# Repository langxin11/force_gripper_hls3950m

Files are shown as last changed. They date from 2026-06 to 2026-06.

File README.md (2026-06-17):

# 基于飞特 HLS3950 的双指力控夹爪

面向飞特 HLS3950 总线舵机的双指力控夹爪项目，包含可测试控制核心、Python 上位机和机械适配资料。当前 CAD 和台架验证以 `HLS3950M-C001` 为基准，官网商品页也写作 `HL-3950-C001`；外形尺寸为 `45.22 mm × 24.72 mm × 35 mm` 且安装、输出轴、通信和供电接口匹配的飞特舵机也可作为候选，例如 `ST-3250-C001`、`ST-3235-C001` 和 `HL-3930-C001`。

> 当前状态：架构与可测试控制骨架已建立，HLS3950 机械适配 CAD 已基本完成；下一阶段使用电脑、飞特 URT-1 和 `vassar-feetech-servo-sdk==1.5.0` 完成尺寸复核、样机装配与真机台架验证。

## 项目来源

本项目基于 [`Shua-Kang/force_gripper_hardware`](https://github.com/Shua-Kang/force_gripper_hardware)
改造而来，当前重点是将原机械结构适配到飞特 HLS3950 及同尺寸候选舵机，并补充控制软件、接线说明和装配文档。
原参考仓库未见明确 `LICENSE` 文件，相关 STEP、STL 和图片资料的使用限制见 [hardware/README.md](hardware/README.md)。

## 仓库结构

```text
firmware/   可移植 C++ 控制核心与单元测试
software/   Python SDK、命令行工具和上位机测试
hardware/   CAD、打印件、接线图和 BOM
docs/       中文架构、适配、装配与开发文档
```

## 快速验证

```bash
cmake -S firmware -B build/firmware
cmake --build build/firmware
ctest --test-dir build/firmware --output-on-failure
uv run --project software --extra dev pytest software/tests -v
```

如果只验证 Python 上位机：

```bash
uv run --project software --extra dev pytest software/tests -v
```

更多开发命令（包括文档构建、静态检查）见[开发与测试](docs/development.md)。

## 文档

- [项目文档首页](docs/index.md)
- [主机通信协议](docs/host-protocol.md)
- [HLS3950 通信适配](docs/hls3950-adaptation.md)
- [机械设计与装配](docs/mechanical.md)
- [URT-1 接线](docs/urt1-wiring.md)
- [开发与测试](docs/development.md)

严格构建文档或启动本地预览：

```bash
uv run --project software --extra docs mkdocs build --strict
uv run --project software --extra docs mkdocs serve
```

## 开源许可

本仓库原创代码、文档和新增设计说明采用 [Apache License 2.0](LICENSE) 发布。
来自 `Shua-Kang/force_gripper_hardware` 的参考 STEP、STL 和图片资料，以及飞特官网图片/PDF 等第三方资料不自动纳入本仓库 Apache-2.0 许可；这些资料的使用限制以其来源说明为准。

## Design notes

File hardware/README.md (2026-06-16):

# 硬件目录

本目录用于存放 HLS3950 版本的机械和电气设计。

- `cad/`：参数化源文件和中性格式 STEP 文件。
- `print_parts/`：经过版本标记的 STL/3MF 打印文件。
- [`BOM.md`](BOM.md)：HLS3950 版本首版样机物料清单。
- `cad/force_gripper_xl430.step`：导入 Onshape 的原 XL430 夹爪装配参考模型。
- `print_parts/` 下的原始 STL：仅用于尺寸和装配校核，不代表已经适配 HLS3950。
- 后续增加接线图、皮带轮工程图和装配公差表。

当前机械适配在 [Onshape 文档](https://cad.onshape.com/documents/6b62f8794d0bbb7b41c1c997/w/e1534e929e40aaacf2109eb3/e/1d43023ae86ad55792d145ee) 中维护。CAD 已基本完成，尚待实物尺寸复核、打印和装配验证。

已实施的核心变更：

- 重新绘制与飞特 HLS3950 连接的基体，使安装孔位匹配舵机。
- 从动轮与基体左右安装耳改用 `5 mm × 35 mm` 光杆、`M4` 螺纹的塞打螺栓，不再使用圆柱销。
- 主动轮改为以轴心为中心、半径 `7 mm`（节圆直径 `14 mm`）的四孔圆周阵列，使用 `M3` 螺丝与舵机连接。

改造参数、复用范围和装配图片统一见[机械设计与装配](../docs/mechanical.md)。

## 参考模型来源

参考文件来自 [`Shua-Kang/force_gripper_hardware`](https://github.com/Shua-Kang/force_gripper_hardware)
提交 `ff68bf4fce071ca1d055616c89dba56ccfd226d8`。该参考仓库当前没有明确的许可证文件，
因此这些文件只用于本项目内部改型和尺寸校核，不受本仓库 Apache-2.0 许可覆盖；公开发布、再分发或商业使用前必须取得原作者授权。

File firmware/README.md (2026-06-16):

# 固件控制核心

可移植 C++17 夹爪控制核心，通过抽象 `ServoBus` 接口与舵机层解耦。

## 结构

```text
core/include/    公开头文件（GripperController、ServoBus 接口）
core/src/        控制核心实现
tests/           单元测试（含 FakeServoBus）
```

## 编译与测试

```bash
cmake -S firmware -B build/firmware
cmake --build build/firmware
ctest --test-dir build/firmware --output-on-failure
```

不依赖硬件，可在任何 C++17 环境编译运行。

## 文档

架构设计见[总体架构](../docs/architecture.md)，开发流程见[开发与测试](../docs/development.md)。

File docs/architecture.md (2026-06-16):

# 总体架构

控制核心使用标准 C++17，通过抽象的 `ServoBus` 访问舵机；具体协议、未来控制板实现和上位机接口与控制逻辑解耦。这样可以在无硬件环境测试状态机，也能在更换通信方案时保留控制逻辑。

## 分层

| 层级 | 职责 | 不应承担的职责 |
| --- | --- | --- |
| 机械与电气 | 安装、传动、供电、接线和散热 | 控制协议和上位机业务逻辑 |
| 舵机总线适配 | HLS3950 帧、寄存器、超时和单位换算 | 夹爪状态机和 ROS 接口 |
| 控制核心 | 双电机协调、限幅、故障处理和后续力控 | 串口驱动和具体寄存器地址 |
| 控制板应用 | 调度控制周期、解析主机命令、发布状态 | 机械参数的隐式硬编码 |
| Python SDK | 稳定的初始化、使能、位置和状态 API | 直接访问舵机总线 |
| ROS 适配 | ROS 话题、服务和参数桥接 | 重复实现控制算法 |

## 数据流

```text
Python/ROS
    | 高层 JSON Lines 命令
控制板应用
    | 调用控制 API
GripperController
    | ServoBus 接口
HLS3950 总线适配
    | 半双工串口
两台 HLS3950
```

命令格式和错误语义详见[主机通信协议](host-protocol.md)。

## 安全边界

- 默认输出关闭，初始化成功后才允许使能。
- 输出在控制核心统一限幅，初始上限为额定范围的 25%。
- 任一电机通信失败时，两侧同时停止并关闭扭矩。
- 故障不能靠下一条普通运动命令自动清除。
- 真机测试必须脱离夹爪传动机构或设置机械限位保护。

当前台架由电脑经 URT-1 运行 `vassar-feetech-servo-sdk==1.5.0`，直接控制 HLS3950。
上图中的 C++ `ServoBus` 数据流对应未来板级控制路线；具体 MCU 或控制板尚未选定。

## 参见

- [HLS3950 通信适配](hls3950-adaptation.md)：舵机底层 SDK 选型和台架验证。
- [主机通信协议](host-protocol.md)：控制板与上位机之间的 JSON Lines 命令定义。
- [开发与测试](development.md)：控制核心的编译测试流程。

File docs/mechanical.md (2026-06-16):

# 机械设计与装配

当前 HLS3950 机械适配已在 [Onshape CAD](https://cad.onshape.com/documents/6b62f8794d0bbb7b41c1c997/w/e1534e929e40aaacf2109eb3/e/1d43023ae86ad55792d145ee) 中基本完成，待实物尺寸复核、打印和装配验证。当前基准型号为 `HLS3950M-C001`，官网商品页也写作 `HL-3950-C001`。同外形尺寸 `45.22 mm × 24.72 mm × 35 mm` 且安装、输出轴、通信和供电接口匹配的飞特舵机也可作为机械候选，例如 `ST-3250-C001`、`ST-3235-C001` 和 `HL-3930-C001`。

## 已实施变更

| 部位 | 当前设计 | 样机检查重点 |
| --- | --- | --- |
| 安装基体 | 按 HLS3950 安装孔位重新绘制 | 孔距、输出轴中心、出线空间和结构强度 |
| 主动轮 | 4 个 M3 孔，孔中心半径 7mm，PCD 14mm | 螺丝长度、避空、防松和同轴度 |
| 从动轮轴 | 5mm × 35mm 光杆、M4 螺纹塞打螺栓 | 光杆覆盖轴承承载区，螺纹不接触轴承工作面 |

还需确认机械限位、皮带张紧量、动力配电安装位，以及舵机和线束与机器人法兰、相机支架的全行程干涉。

## 复用范围

原 XL430 项目的以下内容可作为首版样机参考：

| 内容 | 处理 |
| --- | --- |
| MGN12H 导轨、滑块、指尖支架和 TPU 指尖 | 原则上复用，装配后检查干涉 |
| HTD3M 皮带、从动轮和 F685-2RS 轴承 | 保持传动中心距时复用，最终长度需复核 |
| 指尖、滑块和皮带装配顺序 | 可参考，张紧量和行程需重新验证 |
| 原基体、XL430 主动轮、圆柱销装配和 OpenRB 接线 | 不复用 |

## 打印与装配参考

刚性零件可先用 PLA、PETG 或 ABS，指尖使用 TPU 95A。HLS3950 新基体和主动轮的材料、层方向和填充率需通过样机试验确定。

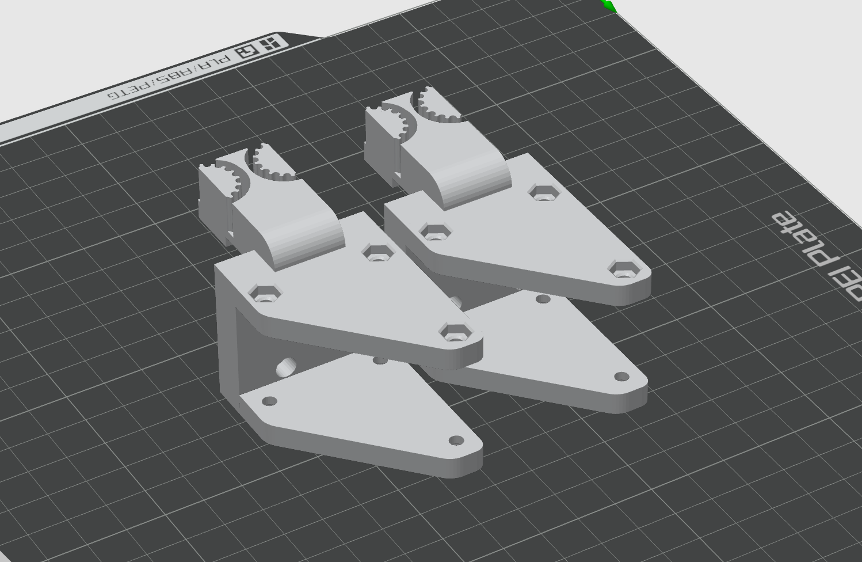
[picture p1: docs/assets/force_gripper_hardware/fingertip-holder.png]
原项目指尖支架打印方向


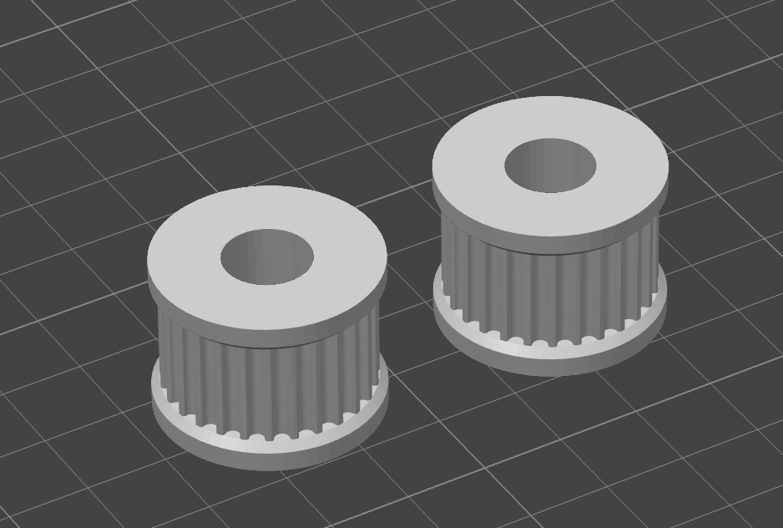
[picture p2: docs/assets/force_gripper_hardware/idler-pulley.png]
原项目从动轮打印方向


从动轮本体可参考，轴和安装方式以当前塞打螺栓方案为准。

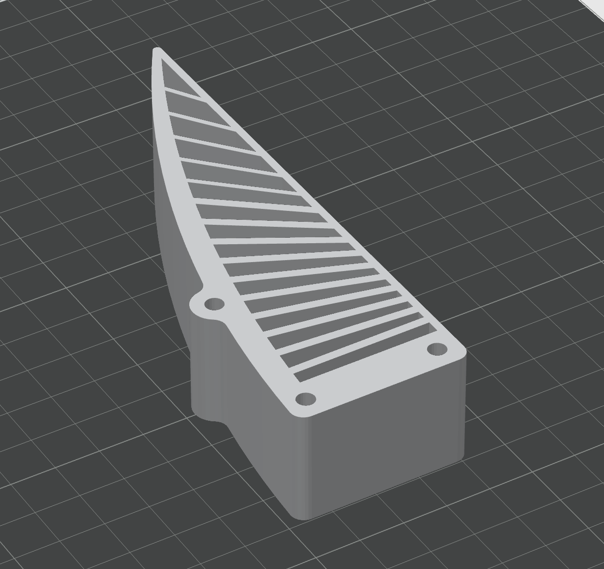
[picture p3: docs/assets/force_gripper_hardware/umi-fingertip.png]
原项目 TPU 指尖打印方向


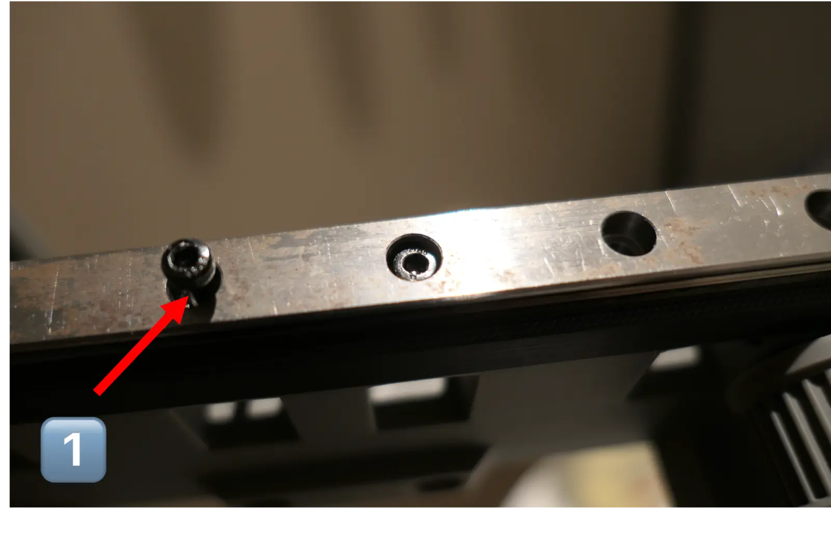
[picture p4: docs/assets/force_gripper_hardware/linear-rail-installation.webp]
原项目线性导轨安装


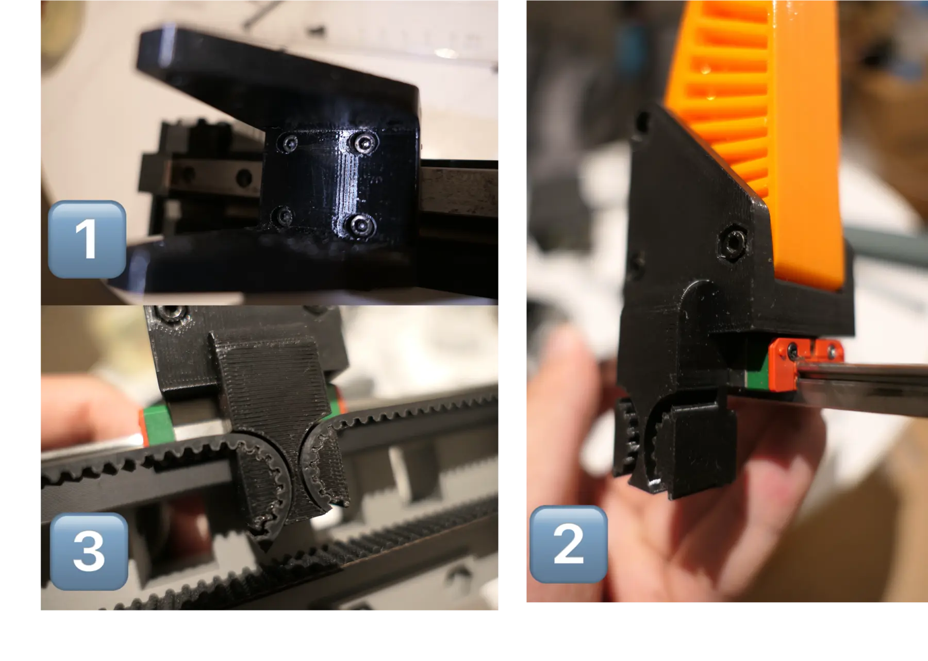
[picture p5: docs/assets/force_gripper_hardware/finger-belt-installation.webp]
原项目指尖和同步带装配


装配后检查导轨螺丝不进入滑块行程，皮带全行程无跳齿、跑偏和干涉。

## 发布前检查

1. 使用 HLS3950 实物复核安装孔、输出轴中心和连接器空间。
2. 确认主动轮、从动轮和皮带夹持点共面，并保留张紧调节量。
3. 确认塞打螺栓光杆覆盖轴承承载区。
4. 验证左右滑块全行程和实体机械限位。
5. 导出完整装配至 `hardware/cad/hls3950_gripper.step`（当前待生成），并将新增打印件导出到 `hardware/print_parts/`。

## 来源限制

参考 STEP、STL 和图片来自 [`Shua-Kang/force_gripper_hardware`](https://github.com/Shua-Kang/force_gripper_hardware) 提交 `ff68bf4fce071ca1d055616c89dba56ccfd226d8`。原仓库没有明确许可证；这些参考资料不受本仓库 Apache-2.0 许可覆盖。公开发布衍生模型或图片前需取得作者授权，或替换为本项目自行生成的资料。图片对应关系见 `docs/assets/force_gripper_hardware/PROVENANCE.txt`。

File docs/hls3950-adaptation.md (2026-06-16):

# HLS3950 通信适配

## 当前路线

电脑通过 `URT-1` 直接连接两台 HLS3950，当前选用社区维护的
[`vassar-feetech-servo-sdk==1.5.0`](https://github.com/vassar-robotics/feetech-servo-sdk)。
该版本同时提供高层 `ServoController` 和底层 `scservo_sdk.hls`。

安装真机依赖：

```bash
uv sync --project software --extra hardware
```

截至 2026-06-15，依赖来源的核对结果如下：

| 来源 | HLS 支持 | 结论 |
| --- | --- | --- |
| 官方 GitHub `FTServo_Python` | 包含 `scservo_sdk/hls.py` 和 `hls/` 示例 | 用于核对底层实现 |
| 官方 PyPI `ftservo-python-sdk==2.0.0` | wheel 和 sdist 均缺少 `scservo_sdk/hls.py` | 不能用于 HLS3950 |
| 社区 PyPI `vassar-feetech-servo-sdk==1.5.0` | wheel 和 sdist 均包含 HLS | 本项目当前选型 |

社区包内置的整个 `scservo_sdk` 目录与飞特官方提交
`a203373036723e0d98c6c49b67cf09a9ee299220` 逐文件一致，可以替代 Git 依赖。
它同样安装顶层 `scservo_sdk` 包，不应与 `ftservo-python-sdk` 同时安装。

当前直接使用社区包的 `ServoController` 开展台架验证，不额外实现包装层。使用时必须明确其行为：

- `connect()` 会检查各舵机相位，并把非零相位改为 `0`。
- `write_position()` 和 `write_torque()` 会按需切换工作模式并使能扭矩。
- `disconnect()` 会关闭所有已配置舵机的扭矩。
- 电流单位、扭矩方向和保护行为仍需使用 HLS3950 实物验证。

```text
电脑 -> USB -> 飞特驱动板/URT -> HLS3950 总线
                    |
                 外部 12V 电源
```

完整供电和引脚要求见 [URT-1 接线](urt1-wiring.md)。USB 串口不保证硬实时，控制频率和急停策略必须通过实测确定。

## 已确认信息

| 项目 | 当前结论 |
| --- | --- |
| 接口 | 三线 TTL，`5264-3P`，GND/Vcc/Signal |
| 电压 | 9V 至 12.6V，正式系统按 12V 设计 |
| 位置范围 | 0 至 4096 对应 360 度 |
| 输出接口 | 25T，外径约 5.9mm |
| SDK 能力 | 位置、速度和同步位置写入 |
| 底层地址 | 模式 33、目标扭矩 44、当前电流 69，仍需按手册和实机核对单位与行为 |

## 软件使用边界

当前仓库尚未实现 HLS3950 专用传输类。台架程序可以直接调用 `ServoController`；夹爪级的双机协调、行程限制、故障联停和力控逻辑仍属于本项目，不由通用舵机 SDK 代替。

## 台架验证顺序

1. 单机只读：扫描 ID，读取型号、位置、电压和温度。
2. 单机低输出：验证扭矩开关、方向、单位和限幅。
3. 单机保护：验证超时、断线、过流和过温行为。
4. 双机通信：验证轮询频率、总线冲突和最坏响应时间。
5. 脱离传动机构完成连续运行测试。
6. 接入皮带后从 10% 输出开始标定开合方向和行程。

## 未决问题

- 寄存器、错误码、反馈单位和符号需与对应硬件版本手册逐项核对。
- HLS3950 是否能以目标频率同时返回位置和电流。
- 恒流模式能否稳定用于低速夹持。
- URT-1 的动力通道持续载流能力，尤其是双机堵转附近的温升。
- URT-1 在双机 1 Mbps 下的稳定性和最大反馈频率。

## 官方资料

- [飞特 HLS3950 产品页与规格书入口](https://www.feetechrc.com/563788.html)
- [飞特 FTServo_Python](https://github.com/ftservo/FTServo_Python)
- [FTServo_Python HLS 模块](https://github.com/ftservo/FTServo_Python/blob/a203373036723e0d98c6c49b67cf09a9ee299220/scservo_sdk/hls.py)
- [官方 PyPI：ftservo-python-sdk](https://pypi.org/project/ftservo-python-sdk/)
- [社区 SDK：vassar-feetech-servo-sdk](https://github.com/vassar-robotics/feetech-servo-sdk)

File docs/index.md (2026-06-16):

# 基于飞特 HLS3950 的双指力控夹爪

本项目使用两台飞特 HLS3950 总线舵机构建双指力控夹爪，目标是让控制、通信和机械设计均可独立验证。当前设计以 `HLS3950M-C001` 为基准，官网商品页也写作 `HL-3950-C001`；外形尺寸为 `45.22 mm × 24.72 mm × 35 mm` 且安装、输出轴、通信和供电接口匹配的飞特舵机也可作为候选，例如 `ST-3250-C001`、`ST-3235-C001` 和 `HL-3930-C001`。

## 当前状态

- 软件：C++ 控制核心、Python SDK、CLI、仿真后端和自动测试已建立。
- 机械：HLS3950 基体、主动轮和从动轮结构的 CAD 适配已基本完成。
- 下一步：复核实物尺寸，完成打印装配，并验证 URT-1 双机通信、供电和反馈频率。

## 阅读顺序

1. [总体架构](architecture.md)与[主机通信协议](host-protocol.md)：了解软件分层、安全策略和命令格式。
2. [HLS3950 通信适配](hls3950-adaptation.md)与 [URT-1 接线](urt1-wiring.md)：进行台架测试。
3. [机械设计与装配](mechanical.md)：查看 CAD 变更、复用件和装配要求。
4. [开发与测试](development.md)：运行测试和提交前检查。

在完成官方资料核对和样机验证前，不假设 HLS3950 兼容 DYNAMIXEL，也不把恒流模式直接等同于夹持力控制。

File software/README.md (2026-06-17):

# HLS3950 Gripper Python SDK

HLS3950 力控夹爪的 Python 上位机 SDK 和命令行工具。

## 目录结构

```text
src/hls3950_gripper/    SDK 包（client、transport、cli）
tests/                   单元测试
```

## 快速开始

零依赖仿真测试：

```bash
uv run --project software --extra dev pytest software/tests -v
PYTHONPATH=software/src python3 -m hls3950_gripper.cli --simulate status
```

真机台架依赖（需要 HLS3950 和 URT-1）：

```bash
uv sync --extra hardware
```

## 文档

完整设计、协议和开发流程见[项目文档](../docs/index.md)。

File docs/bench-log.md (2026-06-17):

# HLS3950 台架记录

## 2026-06-17 双机装带后验证

- 两台舵机已完成 ID 分配：左侧 `ID 1`，右侧 `ID 2`。
- 重新安装同步带前，两台舵机先转到中位 `2047`。
- 同步带安装后，只读轮询确认两台舵机均稳定在 `position=2047` 附近。
- 双机 `close --delta 20` 验证通过：两台舵机均向闭合方向运动，最终误差约 `1-2` tick。
- 双机 `open --delta 20` 验证通过：两台舵机均回到中位附近，最终误差约 `0-1` tick。
- 当前方向映射：`open` 为两台舵机位置减小，`close` 为两台舵机位置增大。
- 当前软件全开参考位暂定为 `left.open_position=2047`、`right.open_position=2047`。
- `close_position` 尚未完成标定，不能用于归一化控制。

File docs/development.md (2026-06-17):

# 开发与测试

## 固件核心

控制核心只依赖标准 C++17，可以在没有控制板和舵机的电脑上编译测试：

```bash
cmake -S firmware -B build/firmware
cmake --build build/firmware
ctest --test-dir build/firmware --output-on-failure
```

新增控制逻辑时，应先使用 `FakeServoBus` 覆盖正常、断线和部分写入失败场景，再接入后续真实总线实现。

## Python 上位机

零依赖测试和仿真命令：

```bash
uv run --project software --extra dev pytest software/tests -v
PYTHONPATH=software/src python3 -m hls3950_gripper.cli --simulate status
```
pytest 兼容 unittest.TestCase，无需改写已有测试。

开发环境安装：

```bash
uv venv
uv pip install -e 'software[dev,docs]'
```

## 提交前检查

首次安装 Git 提交钩子：

```bash
uv run --project software --extra dev pre-commit install
```

钩子会在提交时检查基础文件格式、YAML 和 Python Ruff 规则。也可以手动检查仓库中的全部文件：

```bash
uv run --project software --extra dev pre-commit run --all-files
```

完整检查包括固件与上位机测试、静态检查和文档严格构建：

```bash
cmake -S firmware -B build/firmware
cmake --build build/firmware
ctest --test-dir build/firmware --output-on-failure
uv run --project software --extra dev pytest software/tests -v
uv run --project software --extra docs mkdocs build --strict
uv run --project software --extra dev pre-commit run --all-files
uv run --project software --extra dev mypy software/src
```

依赖下载需要网络；基础 C++ 和 Python 单元测试不需要下载第三方依赖。

如果本机环境会让 `pytest` 自动加载外部插件并导致冲突，可以只对当前命令临时禁用自动加载：

```bash
PYTEST_DISABLE_PLUGIN_AUTOLOAD=1 uv run --project software --extra dev pytest software/tests -v
```

## 参见

- [总体架构](architecture.md)：控制核心的分层设计和安全边界。
- [主机通信协议](host-protocol.md)：命令格式和错误语义。
- [HLS3950 通信适配](hls3950-adaptation.md)：真机 SDK 安装和台架验证顺序。

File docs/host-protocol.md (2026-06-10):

# 主机通信协议

控制板与上位机使用 UTF-8 JSON Lines：每条请求和响应都是一行完整 JSON，以换行符结束。该协议只表达夹爪级命令，不暴露 HLS3950 寄存器。

## 通用响应

成功：

```json
{"ok":true,"status":{"initialized":true,"enabled":false,"fault":null,"left_position":0,"right_position":0}}
```

失败：

```json
{"ok":false,"error":"controller_disabled"}
```

## 命令

初始化：

```json
{"command":"initialize"}
```

使能和关闭：

```json
{"command":"enable"}
{"command":"disable"}
```

查询状态：

```json
{"command":"status"}
```

归一化位置命令：

```json
{"command":"position","left":0.25,"right":0.75}
```

`left` 和 `right` 范围为 `0.0` 到 `1.0`。具体开合方向由标定参数决定，不由上位机猜测电机正反方向。

## 兼容性规则

- 新增字段时，接收方应忽略不认识的可选字段。
- 删除字段或改变字段含义属于破坏性变更，需要增加协议版本。
- 错误使用稳定的机器可读字符串；中文解释由上位机根据错误码显示。
- 控制板必须限制单行最大长度，并对无效 JSON 返回错误而不是执行部分命令。

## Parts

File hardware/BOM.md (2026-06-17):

# HLS3950 力控夹爪 BOM

本文档列出 HLS3950 版本样机物料。

## 电机、控制与通信

| 名称 | 推荐规格 | 数量 | 状态 | 备注 |
| --- | --- | ---: | --- | --- |
| 飞特总线舵机 | HLS3950M-C001，TTL，25T/OD5.9mm 输出花键 | 2 | 必需 | 官网商品页也写作 `HL-3950-C001`；同尺寸兼容候选：`ST-3250-C001`、`ST-3235-C001`、`HL-3930-C001`。 |
| 飞特 USB 总线板 | URT-1 或 URT-2 | 1 | 必需 | 当前原型使用 URT-1。 |
| USB 数据线 | 支持数据传输，接口按总线板实物选择 | 1 | 必需 | URT-1 常见 Mini USB，URT-2 常见 USB-C。 |
| HLS3950 舵机线束  | 5264-3P，GND/Vcc/Signal-TTL | 2 | 可复用 | 舵机自带；不要只按线色接线。 |
| TTL 总线分线/端子 | 3 线并联，GND/Vcc/Signal | 1 | 待 CAD 确认 | 当前原型接法：`12V -> URT-1 DC6V-9V/V1 -> TTL G/S/V -> HLS3950`。 |

## 供电与保护

| 名称 | 推荐规格 | 数量 | 状态 | 备注 |
| --- | --- | ---: | --- | --- |
| 12V 稳压电源 | 12V，至少 6A | 1 | 必需 | 两台舵机堵转电流合计约 4.8A。 |
| 支路保险或电子限流 | 每路按实测峰值选型 | 2 | 必需 | 建议每台舵机独立保护。 |
| 电源线 | 20-22 AWG 或按实测电流升级 | 若干 | 待 CAD 确认 | 按电流与布线长度确定。 |

## 机械传动与标准件

| 名称 | 推荐规格 | 数量 | 状态 | 备注 |
| --- | --- | ---: | --- | --- |
| 线性导轨与滑块 | MGN12H，200mm，含 2 个滑块 | 1 | 可复用 | 沿用原 BOM。 |
| 同步带 | HTD3M，约 1m | 1 | 可复用 | 长度需 CAD 复核。 |
| 法兰轴承 | F685-2RS，5x11x5mm | 2 | 可复用 | 从动同步轮用。 |
| 塞打螺栓 | 光杆直径 5mm，光杆长度 35mm，M4 螺纹 | 1 | 待样机验证 | 从动轮轴。 |
| HTD3M 主动皮带轮 | 四个 M3 连接孔，孔中心半径 7mm，PCD 14mm | 2 | 待样机验证 | 复核孔位、避空和同轴度。 |
| 从动同步轮 | 沿用原 `idler_pulley` 设计 | 1 | 可复用 | 沿用原设计。 |
| 指尖固定座 | 沿用原指尖支架设计 | 2 | 可复用 | 检查限位与干涉。 |
| TPU 指尖 | UMI/FlexiTac 兼容指尖 | 2 | 可复用 | 按传感器需求调整。 |

## 3D 打印件

| 名称 | 数量 | 状态 | 备注 |
| --- | ---: | --- | --- |
| HLS3950 安装基体 | 1 | 待样机验证  | 复核孔径、孔距和出线空间。 |
| HTD3M 主动轮打印体 | 2 | 待样机验证  | 复核强度和偏心。 |
| 从动同步轮 | 1 | 可复用 | `idler_pulley.stl`。 |
| 指尖支架 | 2 | 可复用 | `gripper_fingertip_holder.stl`。 |
| TPU 指尖 | 2 | 可复用 | `umi_fingertip.stl`。 |
| Franka 或 KUKA 法兰转接件 | 1 | 可复用 | 按实际机器人选型。 |
| RealSense 相机支架 | 1 | 可选 | 需要相机时使用。 |
| 配电/URT-1 安装盒 | 1 | 待 CAD 确认 | 按 URT-1 与线束重新设计。 |
| 机械限位或缓冲块 |  2-4 | 必需 | 先于硬碰撞接触。 |

## 紧固件与装配辅料

| 名称 | 推荐规格 | 数量 | 状态 | 备注 |
| --- | --- | ---: | --- | --- |
| M3 螺丝套装 | M3 x 8/10/20/35mm，含螺母 | 1 套 | 可复用 | 新增电机座长度需复核。 |
| HLS3950 安装螺丝 | M2x6mm |  4-8 | 待样机验证  | XL430 的 M2.5 螺丝不能沿用。 |
| 金属螺母或热熔螺母 | 304 六角螺母 M3/M6 | 若干 | 待 CAD 确认 | 反力位置优先用金属件。 |
| 主动轮连接螺丝 | M3，长度按舵机连接面和主动轮厚度选定 | 8 | 待样机验证  | 每个主动轮 4 颗。 |
| M6 法兰安装螺丝 | M6 x 12mm，按机器人法兰选型 |  2-4 | 可复用 | 按机器人法兰选型。 |
| 扎带、胶带、热缩管 | 常规规格 | 若干 | 必需 | 线束固定与应力释放。 |

## 不再作为当前主 BOM 的原 XL430 物料

| 原物料 | HLS3950 版本处理 |
| --- | --- |
| XL430-W250-T | 替换为 2 台 HLS3950M-C001。 |
| 原控制板 | 当前替换为 URT-1。 |
| XL430 随附 M2.5 螺丝 | 不能用于 HLS3950 安装。 |
| XL430 四孔输出盘接口 | 改为四个 M3 孔、半径 7mm、PCD 14mm 的 HLS3950 接口。 |
| 原控制板安装盒 | 不建议直接复用。 |

## 采购前检查项

1. 复核舵机安装孔径、孔距、轴心和出线空间。
2. 复核主动轮孔位、螺丝长度和避空。
3. 复核从动轮轴承与塞打螺栓配合。
4. 按实测电流确定保险、线径和电源余量。
5. 检查舵机、法兰、相机支架和手指张开位干涉。
6. 保留实体机械限位。

## 参考文档

- [HLS3950 通信适配](../docs/hls3950-adaptation.md)
- [URT-1 与 HLS3950 接线](../docs/urt1-wiring.md)
- [机械设计与装配](../docs/mechanical.md)

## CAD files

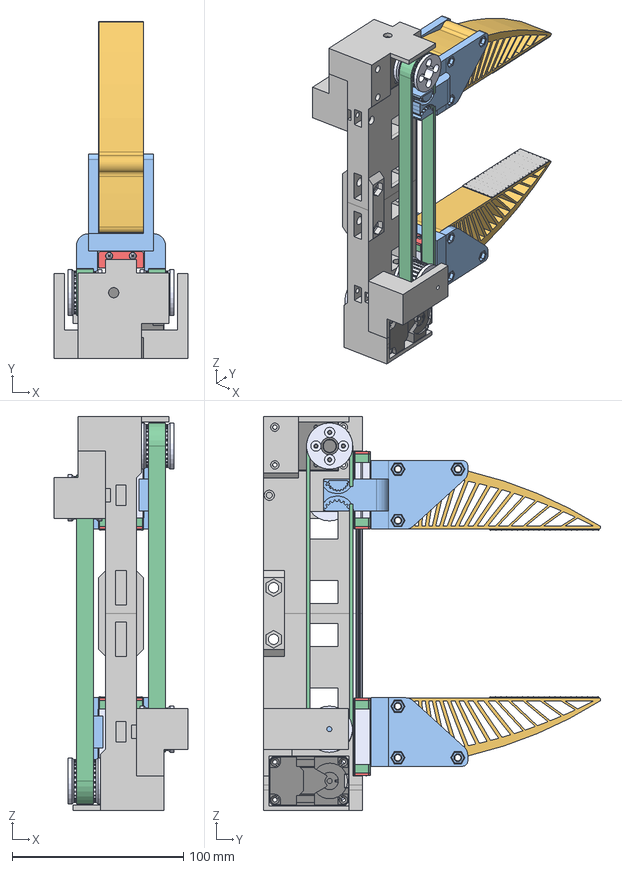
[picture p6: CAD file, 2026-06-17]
hardware/cad/force_gripper_xl430.step
78.0 x 197.0 x 230.0 mm
MGN12 LINEAR GUIDE RAIL, CONFIGURABLE_200 mm x 2
MGN12H, LINEAR GUIDE BLOCK x 2
DC11_A01_DUMMY x 3
DX124_SCREW-COVER x 2
B3B-EH x 4
DC11_A01_CASE_CVR_DUMMY x 2
DC11_A01_IDLER_DUMMY x 2
DC11_A01_IDLER_CAP_DUMMY x 2
DC11_A01_IDLER_SCREW x 2
FHS_M2_5X10 x 16
DC11_A01_SPACER_DUMMY x 16
base x 2
gt2 pulley v1 (1)
HTD3.0 Pulley 18_T 12.000000000000002mm_Belt x 2
HTD3.0 Pulley 27_T 12.000000000000002mm_Belt x 2
HTD3.0 Pulley 18_T 12.000000000000002mm_Belt(Mirror) x 2
holder x 2
soft_gripper_finger x 2
HTD3.0 Pulley 27_T 12.000000000000002mm_Belt (1) x 2
tactilepad x 2

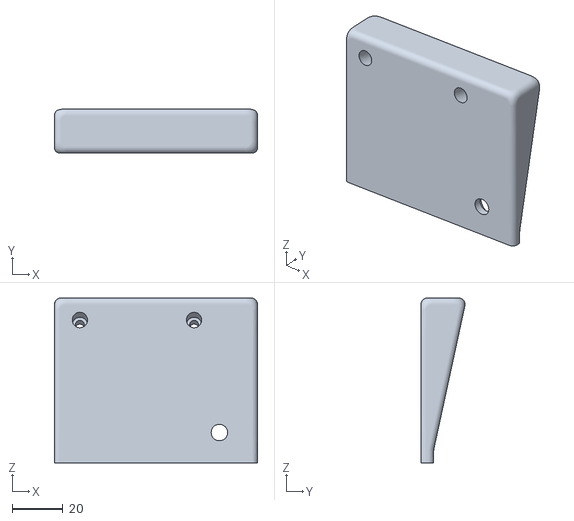
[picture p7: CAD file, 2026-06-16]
hardware/print_parts/realsense_camera_mount.stl
80.0 x 17.4 x 65.0

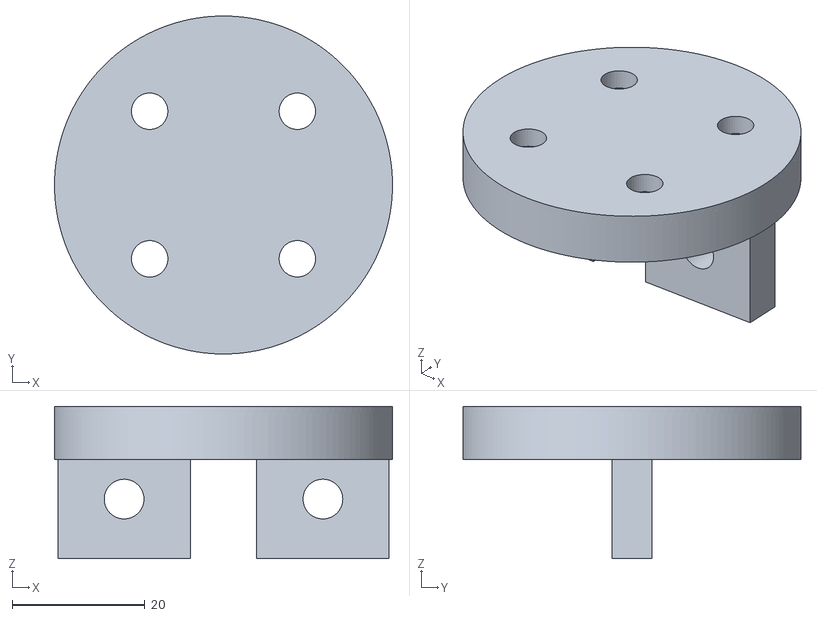
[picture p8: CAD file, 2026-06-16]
hardware/print_parts/kuka_connector.stl
51.0 x 51.0 x 23.0

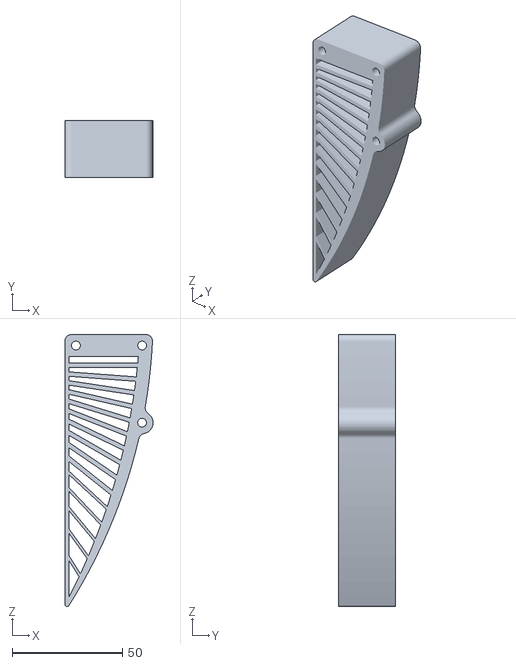
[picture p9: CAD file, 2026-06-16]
hardware/print_parts/umi_fingertip.stl
40.0 x 25.8 x 123.4

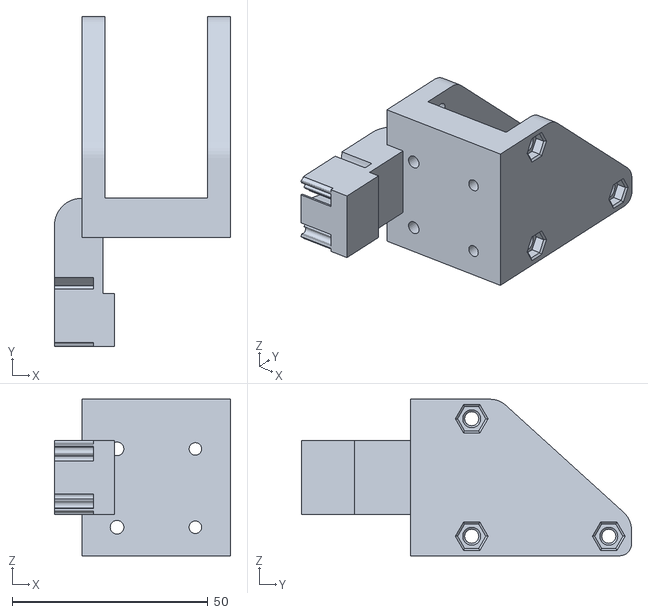
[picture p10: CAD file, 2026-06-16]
hardware/print_parts/gripper_fingertip_holder.stl
45.0 x 84.3 x 40.0

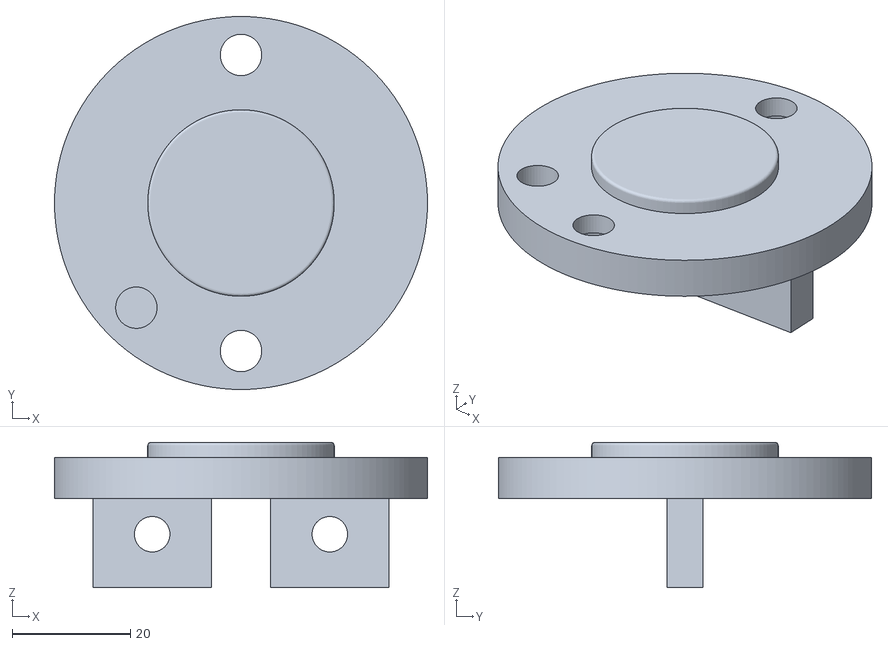
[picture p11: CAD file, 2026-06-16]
hardware/print_parts/franka_connector.stl
63.0 x 63.0 x 24.5

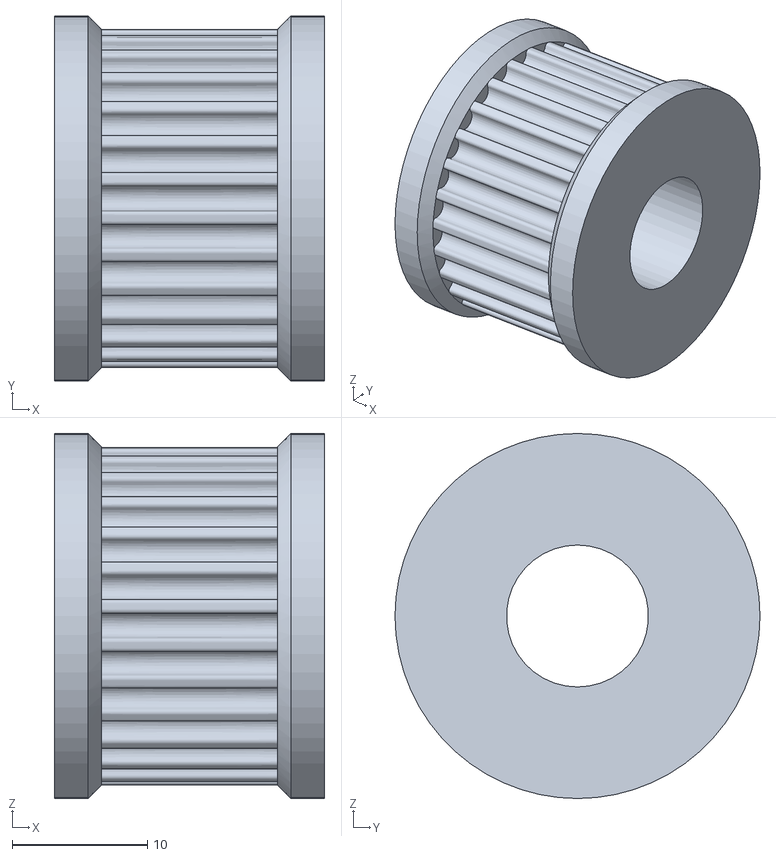
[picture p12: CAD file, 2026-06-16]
hardware/print_parts/idler_pulley.stl
20.0 x 27.0 x 27.0

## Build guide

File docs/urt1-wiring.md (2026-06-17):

# URT-1 与 HLS3950 接线

当前台架通过 USB 连接电脑与飞特 `URT-1`，舵机使用 TTL 总线。数据线接口按实际总线板选择；URT-1 常见为 Mini USB，URT-2 常见为 USB-C。

## 接口识别

URT-1 的 TTL 舵机接口为 `G / S / V`，对应 HLS3950 的 `GND / Signal / Vcc`。当前已实践验证的接法是把
`12V` 电源接入 URT-1 上给 TTL 系列供电的 `DC6V-9V` / `V1` 端子，再通过 TTL 口把 `G / S / V` 一并接到 HLS3950。

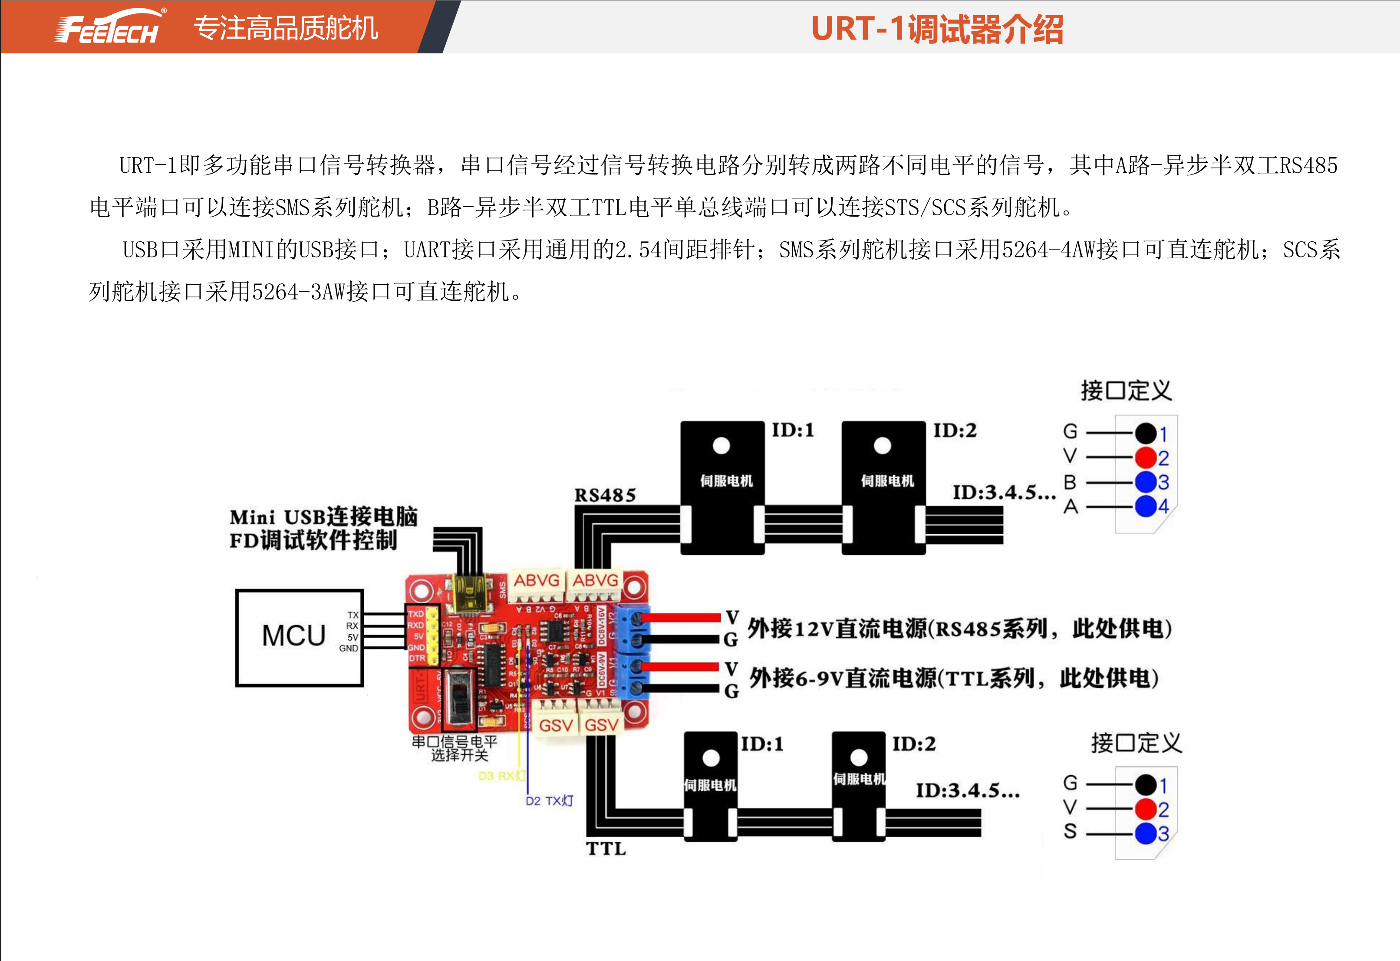
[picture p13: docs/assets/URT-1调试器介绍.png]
飞特 URT-1 调试器接口介绍


飞特 URT-1 调试器接口介绍。

URT-2 可作为同类 USB 总线板候选，接口识别时同样应以板上丝印和对应产品资料为准。

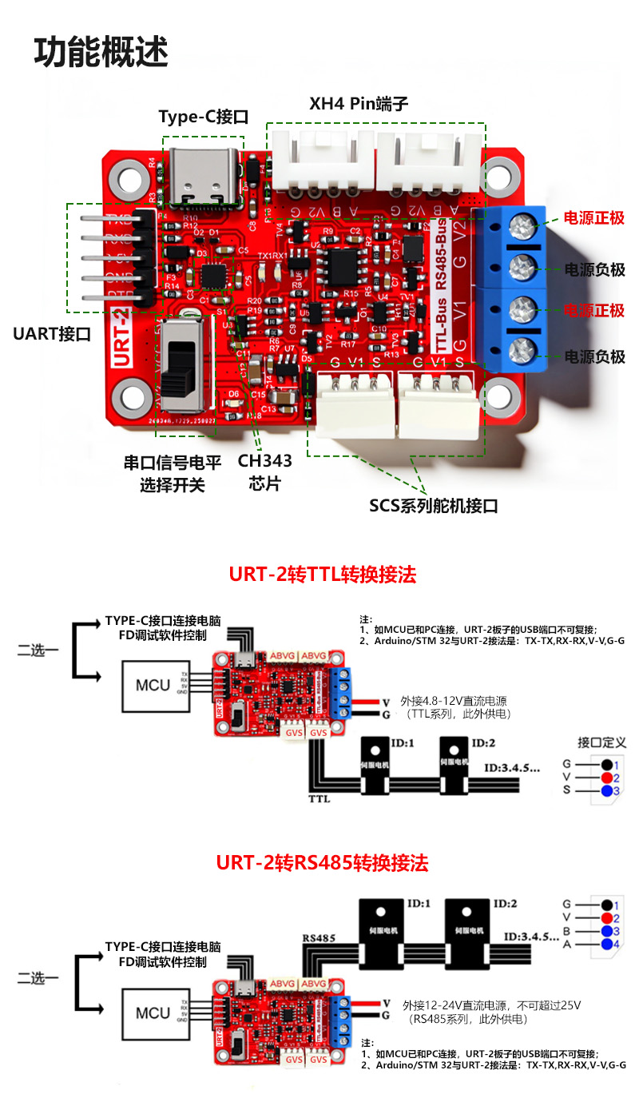
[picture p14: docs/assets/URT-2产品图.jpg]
飞特 URT-2 产品图


来源：飞特官网产品图（本地镜像位于 `docs/assets/`）。

URT-1 关键接口如下：

| URT-1 标识 | 用途 | HLS3950 是否使用 |
| --- | --- | --- |
| Mini USB | 电脑 USB 串口 | 使用 |
| `G / S / V` | TTL 单线总线接口 | 当前接 `G / S / V` 到 HLS3950 |
| `G / V2 / B / A` | RS485 总线接口 | 禁止用于该 TTL 型 HLS3950 |
| `DC6V-9V` / `DC5V-9V` | V1，TTL 系列动力输入 | 当前作为 HLS3950 的 12V 供电入口使用 |
| `8V-24V` / `9V-24V` | RS485 系列供电输入端子 | 当前不用于该 TTL 型 HLS3950 |
| `3V3 / 5V` 开关 | 通信逻辑电平选择 | 当前按 5V |

HLS3950M-C001 官方规格书确认：

- 连接器：`5264-3P`；
- 引脚 1：GND；
- 引脚 2：Vcc；
- 引脚 3：Signal/TTL；
- 工作电压：9V 至 12.6V；
- 信号高电平：2V 至 5V；
- 信号低电平：0V 至 0.45V；
- 默认波特率：1 Mbps；
- 默认 ID：1。

不要只按线色连接，必须核对 URT-1 丝印和舵机规格书。URT-1 的 `3V3 / 5V`
开关只影响 TTL 信号电平，不是舵机供电电压；当前按 5V TTL 连接以获得更大
信号裕量，使用 URT-2 或其他总线板时应按板卡资料和实测通信稳定性确认。

## 12V 外部供电

当前按你已验证的原型接法，`12V` 电源直接接入 URT-1 上给 TTL 系列供电的
`DC6V-9V` / `V1` 端子，再由 TTL 接口的 `G / S / V` 连接 HLS3950。`8V-24V` /
`9V-24V` 端子按当前理解用于 RS485 系列供电，不作为本 TTL 型 HLS3950 的供电入口。
尽管板上 TTL 侧丝印常见为 `DC6V-9V` 或 `DC5V-9V`，你当前样机已验证可接 `12V`
电源；后续仍需结合官方资料和持续温升实测确认长期使用边界。官方说明同时提到
URT-1 的电源端口有过流限制，最大约 `6A`；当前两台 HLS3950 台架验证可以这样接，
后续若增加负载或需要更强保护，再增加独立配电与支路保护。

```text
电脑 USB ───────────────────── URT-1 Mini USB

12V 电源正极 ───────────────── URT-1 DC6V-9V / V1 +
12V 电源负极 ───────────────── URT-1 DC6V-9V / V1 -

URT-1 G ────────────────────── HLS3950 GND
URT-1 S ────────────────────── HLS3950 Signal/TTL
URT-1 V ────────────────────── HLS3950 Vcc
```

两台舵机并联 `GND/Vcc/Signal`，ID 分别设为 1 和 2。建议使用至少 `12V 6A` 的稳压电源，并为各舵机支路增加保险或电子限流；两台舵机官方堵转电流合计约 4.8A。

## 上电顺序

1. 断电状态下检查 `GND/Vcc/Signal` 和电源极性。
2. 确认 URT-1 逻辑电平开关位置；当前按 5V TTL 连接。
3. 初始接线仅连接一台舵机，并确保舵机没有连接夹爪传动机构。
4. 接通舵机电源，确认无异常发热、异味或大电流。
5. 再连接 USB 到电脑，查找串口设备。
6. 先执行只读 `ping`，成功后读取当前位置、电压和温度。
7. 关闭程序、USB 和舵机电源后再改线或增加第二台舵机。

Linux 下可使用以下命令查找稳定设备名：

```bash
ls -l /dev/serial/by-id/
```

初始程序只做 ID 1、1 Mbps 的 `ping` 和只读反馈，不运行运动示例。

## 仍需实测

- URT-1 在双机 1 Mbps 条件下的通信错误率；
- 外部 12V 共地接线下的信号波形；
- 双机位置和电流反馈的持续采样频率；
- URT-1 接口保护和长期温升。

## 官方资料

- [HLS3950 官方产品页](https://www.feetechrc.com/563788.html)
- [HLS3950M-C001 规格书 PDF](https://www.feetechrc.com/Data/feetechrc/upload/file/20240823/6386000661843288188921562.pdf)
- [URT-1 中文使用说明 PDF](https://files.seeedstudio.com/products/Feetech/URT-1%E4%B8%AD%E6%96%87%E4%BD%BF%E7%94%A8%E8%AF%B4%E6%98%8E.pdf)
- [飞特产品手册 2023-02-17 PDF](https://www.feetechrc.com/Data/feetechrc/upload/file/20230218/%E4%BA%A7%E5%93%81%E6%89%8B%E5%86%8C20230217.pdf)
- [飞特 URT-1 调试器介绍图](assets/URT-1调试器介绍.png)
- [飞特 URT-2 产品图](https://www.feetechrc.com/Data/feetechrc/upload/image/20260313/6390901452897617189042771.jpg)
- [FTServo_Python HLS ping 示例](https://github.com/ftservo/FTServo_Python/blob/a203373036723e0d98c6c49b67cf09a9ee299220/hls/ping.py)

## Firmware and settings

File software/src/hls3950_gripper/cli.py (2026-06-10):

from __future__ import annotations

import argparse
import json
from dataclasses import asdict

from .client import GripperClient
from .transport import SerialTransport, SimulatedTransport, Transport


def build_parser() -> argparse.ArgumentParser:
    parser = argparse.ArgumentParser(description="HLS3950 力控夹爪命令行工具")
    parser.add_argument("--port", help="控制器串口，例如 /dev/ttyACM0")
    parser.add_argument("--baudrate", type=int, default=115_200)
    parser.add_argument("--simulate", action="store_true", help="使用内置仿真后端")

    subparsers = parser.add_subparsers(dest="command", required=True)
    for command in ("initialize", "enable", "disable", "status"):
        subparsers.add_parser(command)

    position = subparsers.add_parser("position")
    position.add_argument("left", type=float)
    position.add_argument("right", type=float)
    return parser


def main() -> None:
    args = build_parser().parse_args()
    transport: Transport
    if args.simulate:
        transport = SimulatedTransport()
    elif args.port:
        transport = SerialTransport(args.port, args.baudrate)
    else:
        raise SystemExit("必须提供 --port 或 --simulate")

    client = GripperClient(transport)
    if args.command == "position":
        client.enable()
        status = client.command_position(args.left, args.right)
    else:
        status = getattr(client, args.command)()
    print(json.dumps(asdict(status), ensure_ascii=False, indent=2))


if __name__ == "__main__":
    main()

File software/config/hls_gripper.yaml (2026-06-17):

# HLS3950 gripper software calibration.
#
# These limits are software guard rails for bench control scripts. They are not
# written to servo EEPROM. Replace the placeholder positions after mechanical
# calibration, keeping the range conservative at first.

bus:
  baudrate: 1000000

servos:
  left:
    id: 1
    # Smaller position opens the finger; larger position closes it.
    # Reinstalled belt: both servos were aligned near 2047 at the open pose.
    open_position: 2047
    # TODO: calibrate with incremental close tests before using normalized control.
    close_position: 0
  right:
    id: 2
    # Smaller position opens the finger; larger position closes it.
    # Reinstalled belt: both servos were aligned near 2047 at the open pose.
    open_position: 2047
    # TODO: calibrate with incremental close tests before using normalized control.
    close_position: 0

motion:
  speed: 100
  acc: 5
  torque: 100
  max_step: 50
  tolerance: 20
  poll_interval: 0.1
  timeout: 3.0

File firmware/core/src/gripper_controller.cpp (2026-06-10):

#include "gripper/gripper_controller.hpp"

#include <algorithm>
#include <cmath>

namespace gripper {

GripperController::GripperController(ServoBus& bus, ControllerConfig config)
    : bus_(bus), config_(config) {
    config_.max_effort = std::clamp(std::abs(config_.max_effort), 0.0F, 1.0F);
}

bool GripperController::initialize() {
    disable();
    state_.initialized = false;

    if (!bus_.ping(config_.left_id) || !bus_.ping(config_.right_id)) {
        latchFault(FaultCode::kServoOffline);
        return false;
    }

    state_.fault = FaultCode::kNone;
    state_.initialized = true;
    return true;
}

bool GripperController::enable() {
    if (!state_.initialized || state_.fault != FaultCode::kNone) {
        return false;
    }
    if (!setTorqueForBoth(true)) {
        setTorqueForBoth(false);
        latchFault(FaultCode::kBusWriteFailed);
        return false;
    }
    state_.enabled = true;
    return true;
}

void GripperController::disable() {
    bus_.writeEffort(config_.left_id, 0.0F);
    bus_.writeEffort(config_.right_id, 0.0F);
    setTorqueForBoth(false);
    state_.enabled = false;
}

bool GripperController::commandEffort(float left, float right) {
    if (!state_.enabled || state_.fault != FaultCode::kNone) {
        return false;
    }

    const bool left_ok = bus_.writeEffort(config_.left_id, clamp(left, config_.max_effort));
    const bool right_ok = bus_.writeEffort(config_.right_id, clamp(right, config_.max_effort));
    if (!left_ok || !right_ok) {
        emergencyStop();
        state_.fault = FaultCode::kBusWriteFailed;
        return false;
    }
    return true;
}

bool GripperController::poll() {
    if (!state_.initialized) {
        return false;
    }

    ServoState left{};
    ServoState right{};
    if (!bus_.readState(config_.left_id, left) || !bus_.readState(config_.right_id, right)) {
        emergencyStop();
        state_.fault = FaultCode::kBusReadFailed;
        return false;
    }

    state_.left = left;
    state_.right = right;
    return true;
}

void GripperController::emergencyStop() {
    disable();
    state_.fault = FaultCode::kEmergencyStopped;
}

bool GripperController::clearFault() {
    if (state_.enabled) {
        return false;
    }
    state_.fault = FaultCode::kNone;
    return true;
}

const GripperState& GripperController::state() const {
    return state_;
}

float GripperController::clamp(float value, float limit) {
    return std::clamp(value, -limit, limit);
}

bool GripperController::setTorqueForBoth(bool enabled) {
    const bool left_ok = bus_.setTorqueEnabled(config_.left_id, enabled);
    const bool right_ok = bus_.setTorqueEnabled(config_.right_id, enabled);
    return left_ok && right_ok;
}

void GripperController::latchFault(FaultCode fault) {
    state_.enabled = false;
    state_.fault = fault;
}

}  // namespace gripper

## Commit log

2026-06-10 chore: initialize HLS3950 gripper project
2026-06-10 docs: add URT-1 direct-control wiring
2026-06-16 chore(repo): normalize HLS3950 prototype repository
    - reorganize docs, hardware assets, and reference materials
    - document URT-1 wiring, BOM, and HLS3950-compatible servo notes
    - add Apache-2.0 licensing and refresh CI/MkDocs metadata
    [force_gripper_xl430.step, franka_connector.stl, gripper_fingertip_holder.stl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]
2026-06-17 Add HLS3950 bench diagnostics and wiring fixes
    [hls3950_dual_readonly.py, hls3950_set_id.py, hls3950_single_readonly.py]
2026-06-17 Remove root Makefile and shorten HLS script names
    [hls_dual_readonly.py, hls_set_id.py, hls_single_readonly.py]
2026-06-17 Configure pre-commit lint exceptions
    [force_gripper_xl430.step]
2026-06-17 refactor(software): 提取共享总线模块，新增单机步进测试脚本，注释中文化
    - 新建 src/hls3950_gripper/bus.py 提取 open_bus/require_success/
    resolve_port/read_snapshot/ServoSnapshot，消除三个脚本间的重复代码
    - hls_single_readonly.py / hls_dual_readonly.py / hls_set_id.py 改为
    从 bus 模块导入公用函数，总删除约 455 行冗余代码
    - 新增 hls_single_step.py：单机低风险小步进运动测试脚本，含角度限位
    校验、扭矩使能、轮询等待超时、往返验证等安全机制
    - ping.py 重写为 argparse + bus 模块风格，补齐版权/类型标注/docstring
    - 全部 6 个脚本及 bus.py 的英文注释与 docstring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
    [bus.py, hls_dual_readonly.py, hls_set_id.py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]
2026-06-17 Add HLS gripper calibration helpers
2026-10-02 chore(software): pin development Python version
2026-10-03 ci(software): mypy 显式指定配置文件以生效 ignore_missing_imports
    CI 从仓库根目录运行 mypy，不会读取 software/pyproject.toml 中的
    [[tool.mypy.overrides]]，导致 scservo_sdk / vassar_feetech_servo_sdk
    被误报 import-not-found。改为 --config-file 显式指向该配置。
